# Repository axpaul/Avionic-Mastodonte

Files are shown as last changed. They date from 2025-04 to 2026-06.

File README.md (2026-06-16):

# Mastodonte – Séquenceur

**Mastodonte** est un ordinateur de bord, ou plus précisément un **séquenceur**, destiné à orchestrer de manière autonome les événements critiques d’un vol de fusée expérimentale. Il est conçu pour répondre aux exigences du **cahier des charges du C'Space**, et s’intègre à tout projet nécessitant un séquencement fiable, robuste et temps réel.

---

> *© 2025/2026 - Paul Miailhe.*  
> *This material is licensed under the CERN Open Hardware Licence Version 2 - Strongly Reciprocal (CERN-OHL-S). [→ CERN-OHL-S](https://ohwr.org/licences/)*
> > 

---

<p align="center">
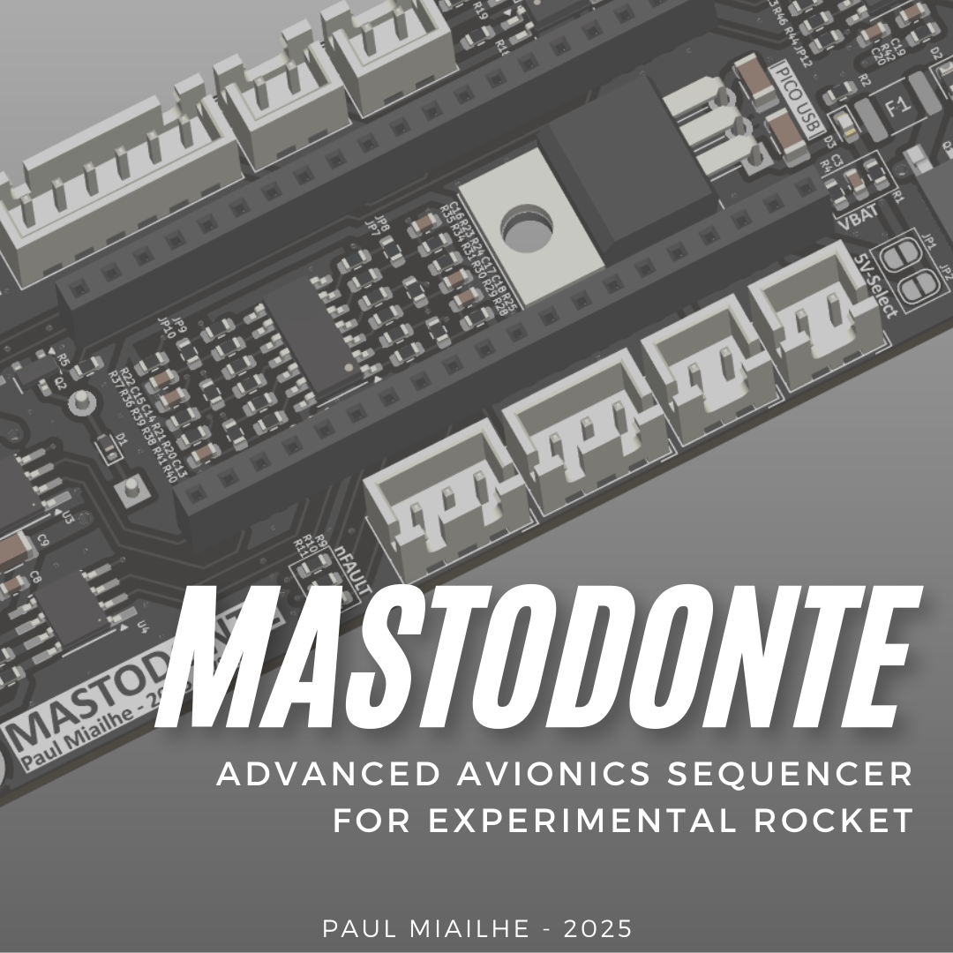
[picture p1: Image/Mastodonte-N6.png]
Carte Mastodonte
  
</p>

---

## Fonctionnement

Mastodonte supervise et déclenche en toute autonomie les étapes clés du vol, sans intervention extérieure :

### Détection du décollage
La détection initiale peut se faire par deux méthodes :
- Un **contact jack** (fil coupe-circuit) : un câble fin relie la fusée au sol, et se sectionne au moment du lancement. La coupure génère une interruption matérielle, qui marque le T-0 du vol.
- Un **accéléro-contact** (contacteur à masselotte) peut également déclencher le séquenceur dès détection d’une accélération.

Dans les deux cas, la carte démarre son chronomètre interne pour initier la séquence.

### Fenêtrage temporel autour de l’apogée
Après le décollage, Mastodonte ouvre une **fenêtre temporelle** durant laquelle la détection de l’apogée est autorisée :
- Un signal extérieur, par exemple issu d’un autre système avionique ou d’un capteur, peut être reçu via un **optocoupleur** pour indiquer l’apogée.
- Ce signal n’est pris en compte **que pendant la fenêtre**, afin d’écarter toute détection parasite en dehors de cette phase critique.
- Si aucune détection n’est reçue, un **déclenchement de sécurité** est effectué après un **temps maximal prédéfini** post-apogée, garantissant ainsi l’ouverture du système de récupération.

### Déploiement du système de récupération
En réponse à une détection d’apogée (ou par sécurité en fin de fenêtre), Mastodonte déclenche le système de récupération :
- Par **charge pyrotechnique** (détonateur, coupe-corde, etc.),
- Ou par **moteur DC** (vis de poussée, libération mécanique, etc.).

### Enregistrement des événements critiques
Mastodonte assure un enregistrement précis des points clés du vol :
- Heure de **décollage** (T-0),
- **Début et fin** de la fenêtre d’apogée,
- **Réception (ou absence)** du signal d’apogée,
- **Déclenchement** du système de récupération,
- **Tension batterie** mesurée durant le vol,
- **Événements d’erreur moteur** détectés.

Ce journal d’exécution agit comme une **boîte noire embarquée**, permettant d’analyser a posteriori le bon déroulement de la mission, et d’identifier toute anomalie de comportement.

---

> Mastodonte vise à offrir un **fonctionnement déterministe**, **fiable** et **autonome**, même en l’absence de télémétrie ou de supervision au sol, conformément à l’esprit du **cahier des charges C'Space**.

---

## Architecture & Fonctionnalités

### Alimentation et protections
- Protection contre l’inversion de polarité (MOSFET P **SQD50P04-13L**)
- Protection contre surtensions (**TVS SMAJ14A**)
- Limitation de courant via fusible réarmable
- Régulation de tension (LM340AT : 7.4 V batterie → 5 V)
- Sélection de la source d’alimentation (USB-C ou batterie)
- LED d’indication d’alimentation

### Microcontrôleur RP2040-YD

Mastodonte s’appuie sur la carte **RP2040-YD**, une carte commerciale compacte embarquant un microcontrôleur **RP2040** de Raspberry Pi, accompagnée de ses périphériques essentiels :

- Double cœur **ARM Cortex-M0+** cadencé à 133 MHz
- **128 Mbits (16 MB)** de mémoire flash externe **W25Q128**
- Oscillateur intégré à **12 MHz**
- Interface native **USB-C**
- Format physique compatible **Raspberry Pi Pico**
- Brochage latéral avec **40 broches GPIO** (20 de chaque côté)
- LED RGB **WS2812** intégrée (GPIO23)
- Boutons embarqués :
  - **BOOT**
  - **RESET**
  - **USER KEY** (GPIO24)
- Interface **SWD** pour débogage

La carte **RP2040-YD** est conçue pour venir se **connecter verticalement** sur le PCB principal appelé **BR-Motor** via deux rangées de connecteurs femelles. Une fois assemblée, l'ensemble forme la carte **Mastodonte**, regroupant la logique de contrôle (RP2040-YD) et l’électronique de puissance et d’interface (BR-Motor).

<p align="center">
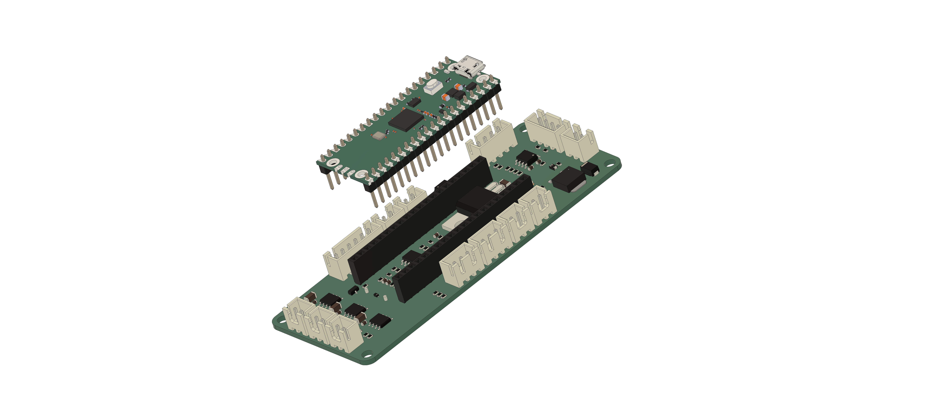
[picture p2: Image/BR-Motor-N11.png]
RP2040-YD plug sur BR-Motor
  
</p>

### Interfaces et connectiques
- Connecteurs au format **JST B2B-XH**
- Connexions dédiées pour moteurs, charges pyrotechniques, capteurs et interfaces de communication
- Tensions disponibles : **5 V** et **3.3 V**

---

## Interfaces et E/S

### Commande moteur / Charge pyrotechnique
- 3 drivers **DRV8872DDA** (ponts en H)
  - Jusqu’à **3.6 A** sous **6.5–45 V**
  - Contrôle **PWM**
  - LED de direction pour visualisation sans charge
  - Détection d’erreurs via broche **nFAULT**

### Signaux d’entrée isolés
- **Optocoupleurs ACPL-214** pour isolation galvanique
- Buffers logiques **74HC14** (Schmitt trigger) pour traitement numérique
- Isolation UART et conversion de niveau : **ADuM1281**
- Pull-ups 4.7 kΩ intégrés sur les lignes I²C

### Buzzer de notification
- Pilotage via transistor **BSS138**
- Protection par diode **1N4148**
- Activation par GPIO (IN_BUZZ)

---

## Schéma fonctionnel

<p align="center">
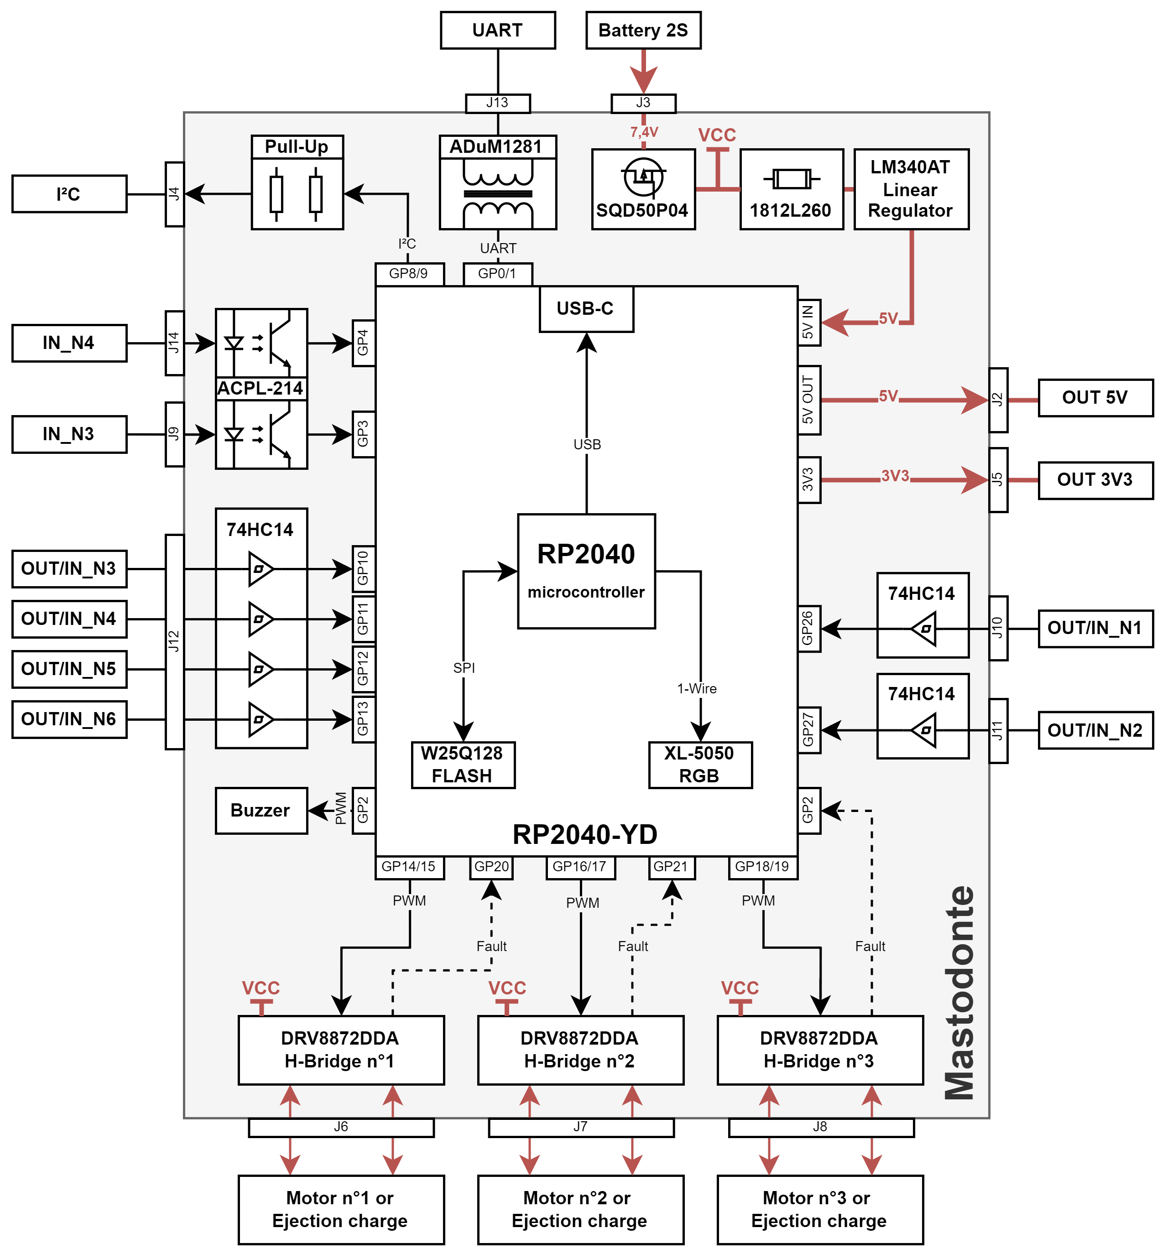
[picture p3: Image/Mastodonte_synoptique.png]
Synoptique Mastodonte
  
</p>

---

## Signaux sortants – Carte Mastodonte (RP2040-YD)

| Signal | Type de signal | Connecteur | GPIO RP2040 | Description |
|---|---|---|---|---|
| `IN1_M1` | PWM / Logique | J6 (Moteur 1) | GP14 | Commande H-Bridge moteur/charge 1 |
| `IN2_M1` | PWM / Logique | J6 (Moteur 1) | GP15 | Commande H-Bridge moteur/charge 1 |
| `IN1_M2` | PWM / Logique | J7 (Moteur 2) | GP16 | Commande H-Bridge moteur/charge 2 |
| `IN2_M2` | PWM / Logique | J7 (Moteur 2) | GP17 | Commande H-Bridge moteur/charge 2 |
| `IN1_M3` | PWM / Logique | J8 (Moteur 3) | GP18 | Commande H-Bridge moteur/charge 3 |
| `IN2_M3` | PWM / Logique | J8 (Moteur 3) | GP19 | Commande H-Bridge moteur/charge 3 |
| `IN_BUZZ` | Logique | J5 (Buzzer) | GP2 | Commande du buzzer (MOSFET BSS138) |
| `OUT_N1` | GPIO | J10 | GP26 | Sortie numérique non isolée |
| `OUT_N2` | GPIO | J10 | GP27 | Sortie numérique non isolée |
| `OUT_N3` | GPIO | J10 | GP10 | Sortie numérique non isolée |
| `OUT_N4` | GPIO | J11 | GP11 | Sortie numérique non isolée |
| `OUT_N5` | GPIO | J11 | GP12 | Sortie numérique non isolée |
| `OUT_N6` | GPIO | J11 | GP13 | Sortie numérique non isolée |
| `OUT_ISO_N3` | GPIO isolée | J13 (Opto) | GP3 | Sortie isolée via optocoupleur |
| `OUT_ISO_N4` | GPIO isolée | J13 (Opto) | GP4 | Sortie isolée via optocoupleur |
| `SDA` | I²C (données) | J12 (I²C) | GP8 | Bus I²C données (avec pull-up) |
| `SCL` | I²C (horloge) | J12 (I²C) | GP9 | Bus I²C horloge (avec pull-up) |
| `IN_ISO_N1` | UART (émission) | J9 (UART) | GP0 | Émission isolée série vers modules externes |
| `OUT_ISO_N2` | UART (réception) | J9 (UART) | GP1 | Réception isolée série depuis modules externes |
| `VCC_BAT` | Alimentation | J2 / J3 (OUT PWR) | — | Tension batterie (après filtrage) exposée |
| `+5V` | Alimentation régulée| J2 / J3 / I²C | — | Tension 5 V régulée disponible |
| `+3.3V` | Alimentation logique| Tous connecteurs  | — | Tension logique (niveau RP2040) |

> Tous les signaux sont sur le standart CMOS 3.3 V côté logique.

## RP2040-YD PINOUT

<p align="center">
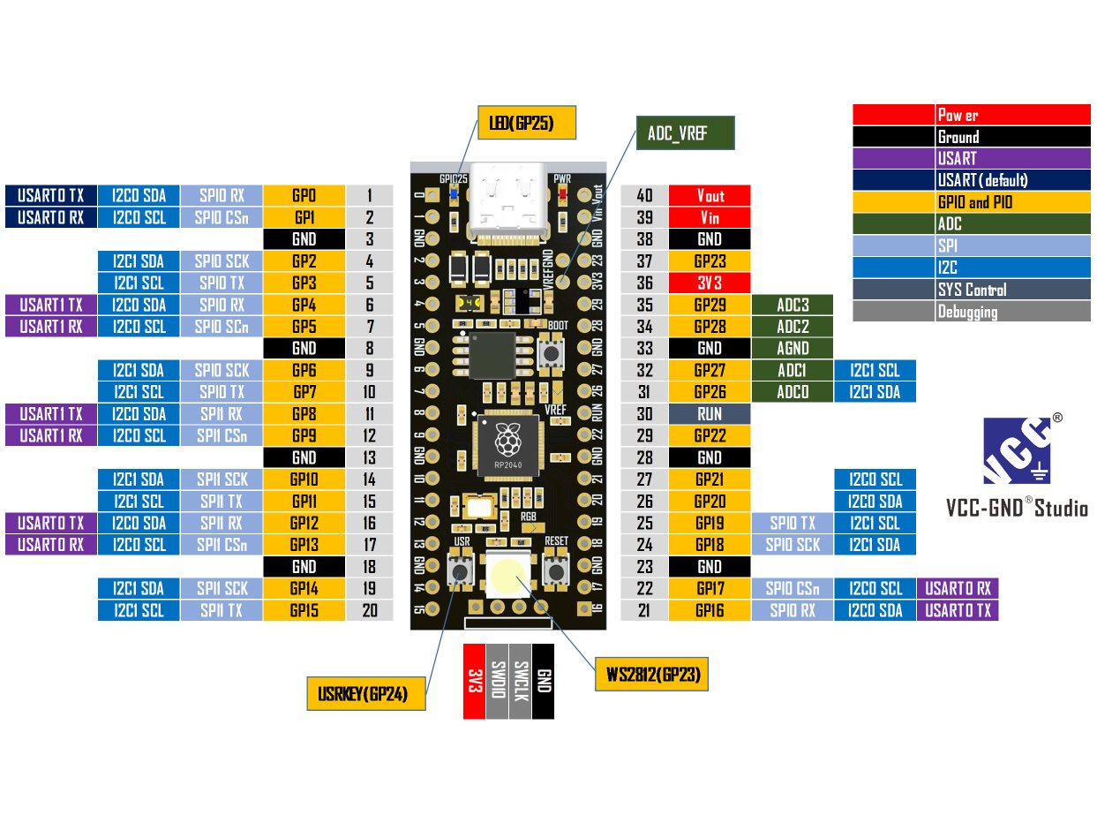
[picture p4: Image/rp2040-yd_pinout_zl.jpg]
RP2040-YD board
  
</p>

---

## Caractéristiques mécaniques

- Dimensions : **100 × 40 mm**
- Épaisseur maximale : **18.13 mm**
- Trous de fixation : 4 × Ø3.2 mm
- Masse sans support : **37 g**
- Fichier **STEP 3D** disponible ici : [`Mechanical/BR-Motor.step`](Mechanical/BR-Motor.step)

<p align="center">
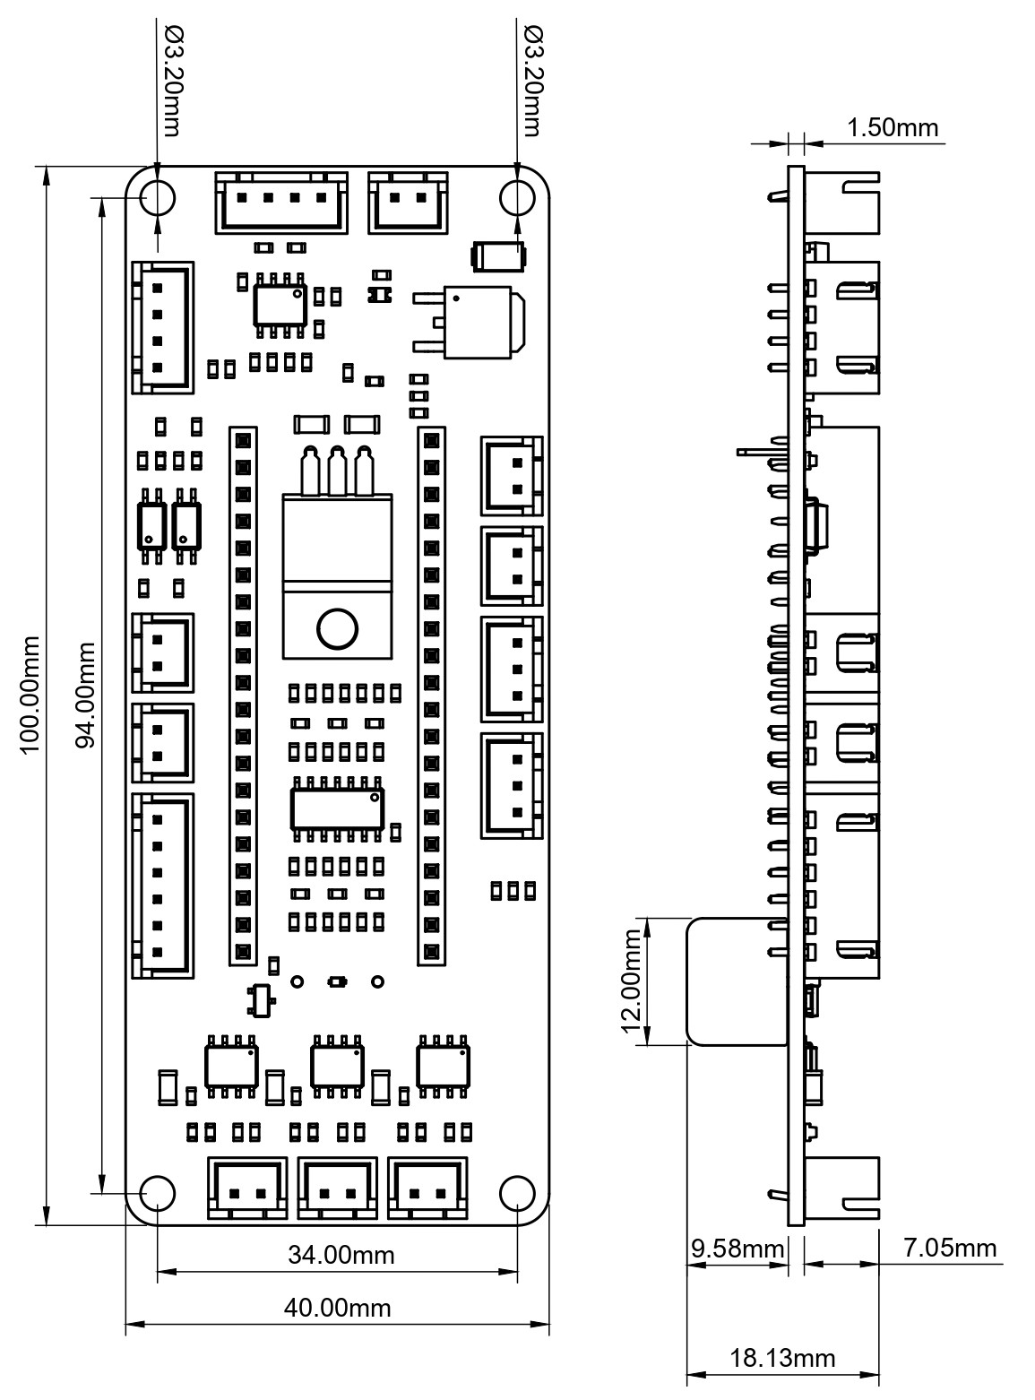
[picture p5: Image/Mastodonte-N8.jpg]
Dimensions mécaniques
  
</p>

---

## Ressources utiles

Composants utilisés sur la carte Mastodonte, avec leurs fiches techniques officielles :

| Composant | Rôle dans le système | Fiche technique |
|---|---|---|
| **DRV8872** | Driver de moteur DC (pont en H jusqu’à 3.6 A) | [→ Datasheet TI](https://www.ti.com/lit/ds/symlink/drv8872.pdf) |
| **RP2040** | Microcontrôleur principal double cœur | [→ Datasheet Raspberry Pi](https://www.raspberrypi.com/documentation/microcontrollers/rp2040.html) |
| **ACPL-214** | Optocoupleur pour isolation galvanique des signaux d’entrée | [→ Datasheet Broadcom](https://www.broadcom.com/products/optocouplers/industrial-plastic/acpl-214) |
| **TLP292(TPL,E** | Optocoupleur pour isolation galvanique des signaux d’entrée | [→ Datasheet Toshiba](https://toshiba.semicon-storage.com/info/TLP292_datasheet_en_20191129.pdf?did=14425&prodName=TLP292) |
| **74HC14** | Buffer logique à trigger de Schmitt pour traitement des signaux numériques | [→ Datasheet TI](https://www.ti.com/lit/ds/symlink/sn74hc14.pdf?ts=1743611017766) |
| **ADuM1281** | Isolateur numérique double canal pour signaux UART | [→ Datasheet Analog Devices](https://www.analog.com/media/en/technical-documentation/data-sheets/ADuM1280_1281_1285_1286.pdf) |
| **LM340AT** | Régulateur de tension linéaire 5V | [→ Datasheet TI](https://www.ti.com/lit/ds/symlink/lm340.pdf) |
| **1812L260/16MR** | Fusible réarmable pour limitation de courant | [→ Datasheet Littelfuse](https://www.littelfuse.com/assetdocs/resettable-ptcs-1812l-datasheet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) |
| **SQD50P04-13L** | MOSFET P pour protection contre l’inversion de polarité | [→ Datasheet Vishay](https://www.vishay.com/docs/65157/sqd50p04-13l.pdf) |
| **BSS138** | Transistor N-MOS pour commutation de charges faibles (buzzer, etc.) | [→ Datasheet OnSemi](https://www.onsemi.com/pdf/datasheet/bss138-d.pdf) |

> Sur la production 02/03/2025, les optocoupleurs utilisés sont les TLP292(TPL,E).

---

# [OPTION] : BR Mini Sensor

La **BR Mini Sensor** est une carte mezzanine entièrement compatible avec la Raspberry Pi Pico. Il s'agit d'un **COMPLEMENT**. Le stack sans fonctionne parfaitement sans, mais cet ajout permet d'étendre ses capacités.
Elle embarque une suite de capteurs communicant via le bus **I²C** :
* **Un accéléromètre 3 axes & un gyromètre 3 axes** (IMU) : Basés sur le composant **LSM6DSL** de STMicroelectronics.
* **Un capteur de pression** permettant de mesurer l'altitude : Basé sur le composant **LPS22HB** de STMicroelectronics.

<p align="center">
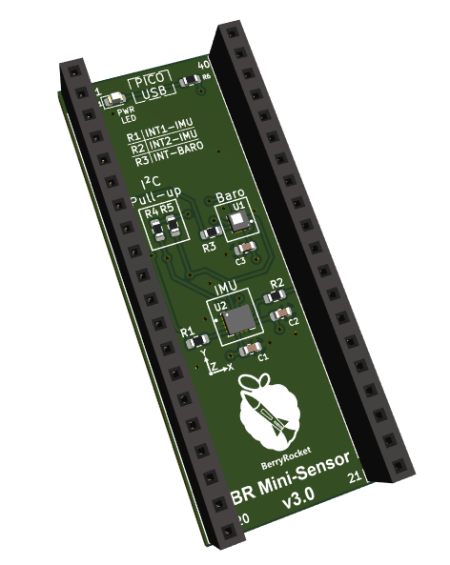
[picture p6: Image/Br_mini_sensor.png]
BR Mini Sensor
  
</p>

La carte BR Mini Sensor vous permettra, moyennant un peu de code, de mesurer et d'enregistrer les paramètres de vol de votre fusée afin d'en estimer la trajectoire.
Pour plus de détails, consultez la documentation officielle : [Wiki BR Mini Sensor](https://berryrocket.com/wiki/BR_Mini_Sensor).

## Configuration matérielle et précautions

Lors de l'intégration de la carte, une attention particulière doit être portée à la gestion des broches d'interruption :

* **Isolement des interruptions (INT1 / INT2) :** Il est nécessaire de prévoir le **dessoudage de certaines résistances 0R** sur la carte pour les lignes `INT1` et `INT2` de l'IMU.
* **Prévention des conflits :** Cette modification permet d'éviter de polluer d'autres pins de la carte BR-Motor et d'interférer avec l'**optocoupleur** ou le signal **Nfault du moteur 3**.

---

## Test Fly Video

La vidéo de qualification de Mastodonte pour le projet Diamant :

### [Visionner le Test Avionique Mastodonte sur YouTube](https://www.youtube.com/watch?v=LKwvPUTVWk4)

<p align="center">
  <a href="https://www.youtube.com/watch?v=LKwvPUTVWk4">
    Test Avionique Mastodonte
  </a>
</p>

*Test des systèmes embarqués de la fusée Mastodonte.*

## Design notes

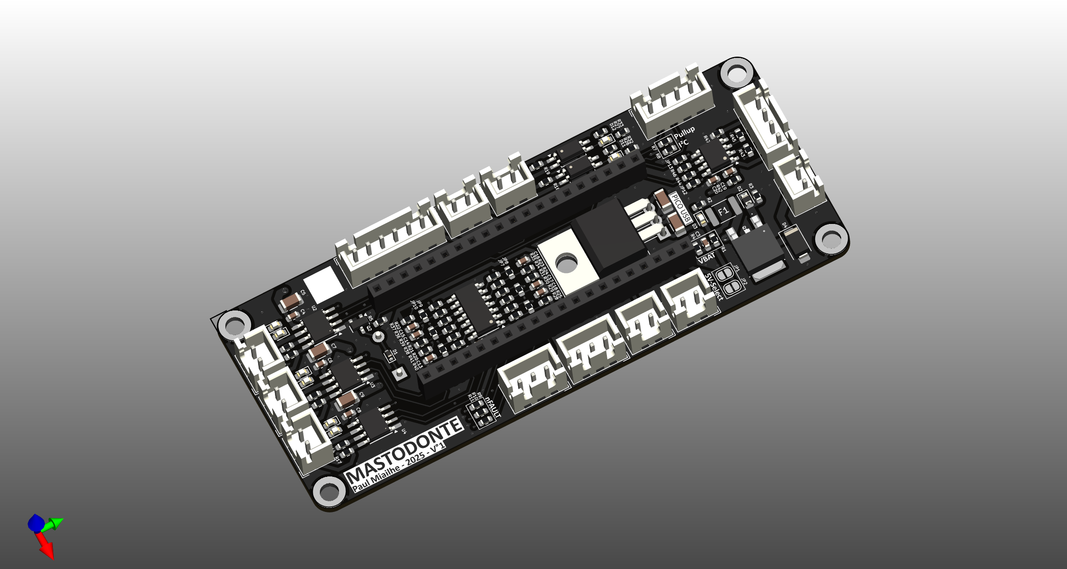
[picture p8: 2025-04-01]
Image/BR-Motor-N8.png

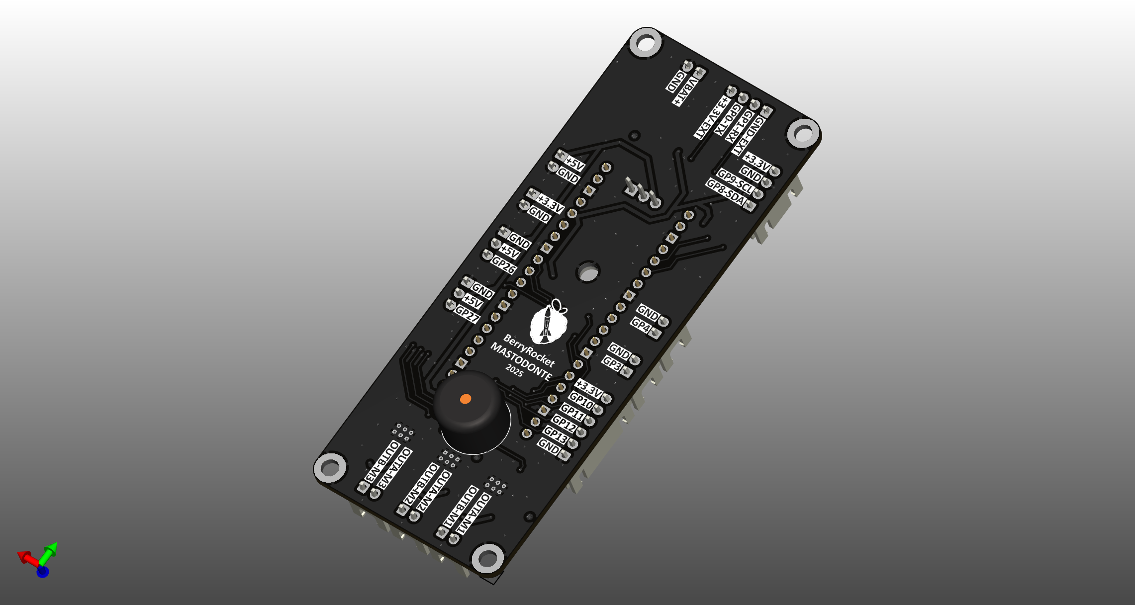
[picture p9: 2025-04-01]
Image/BR-Motor-N9.png

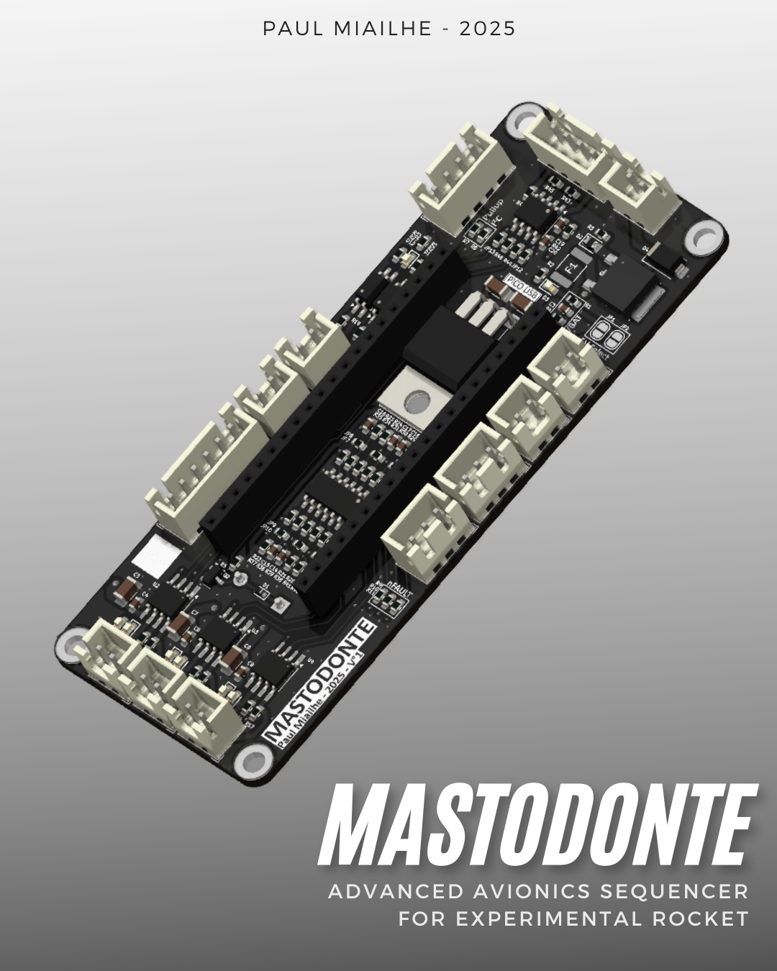
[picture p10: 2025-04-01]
Image/Mastodonte-N1.png

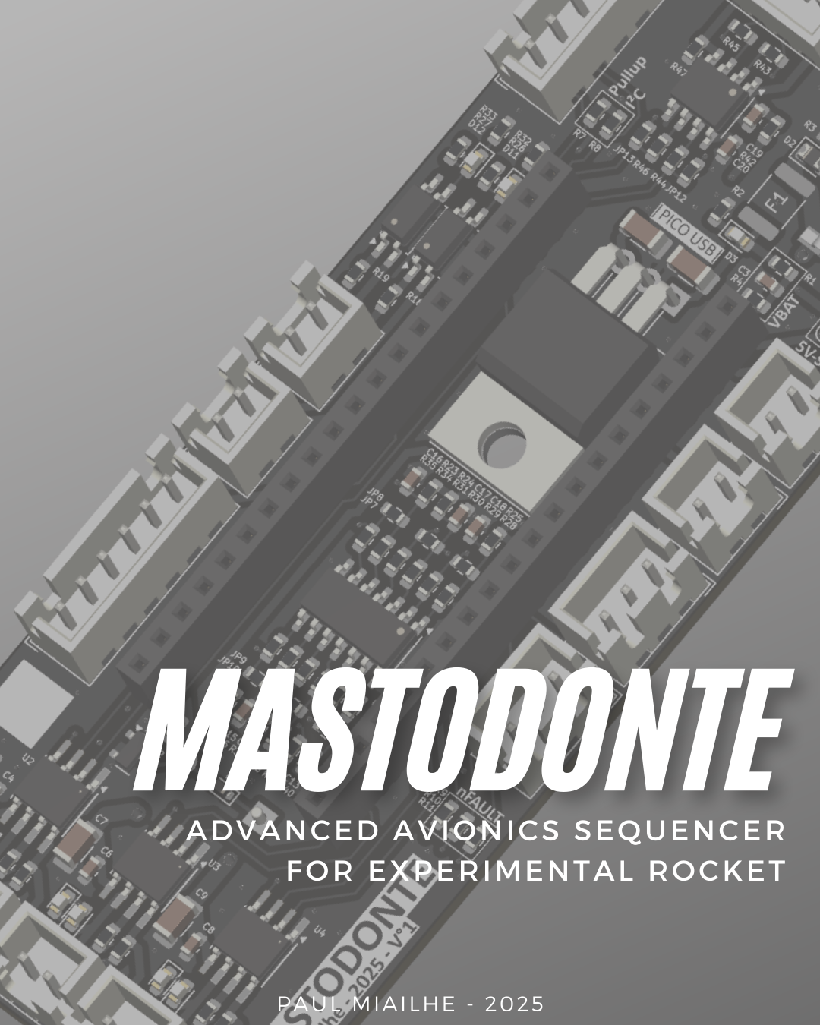
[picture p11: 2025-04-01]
Image/Mastodonte-N4.png

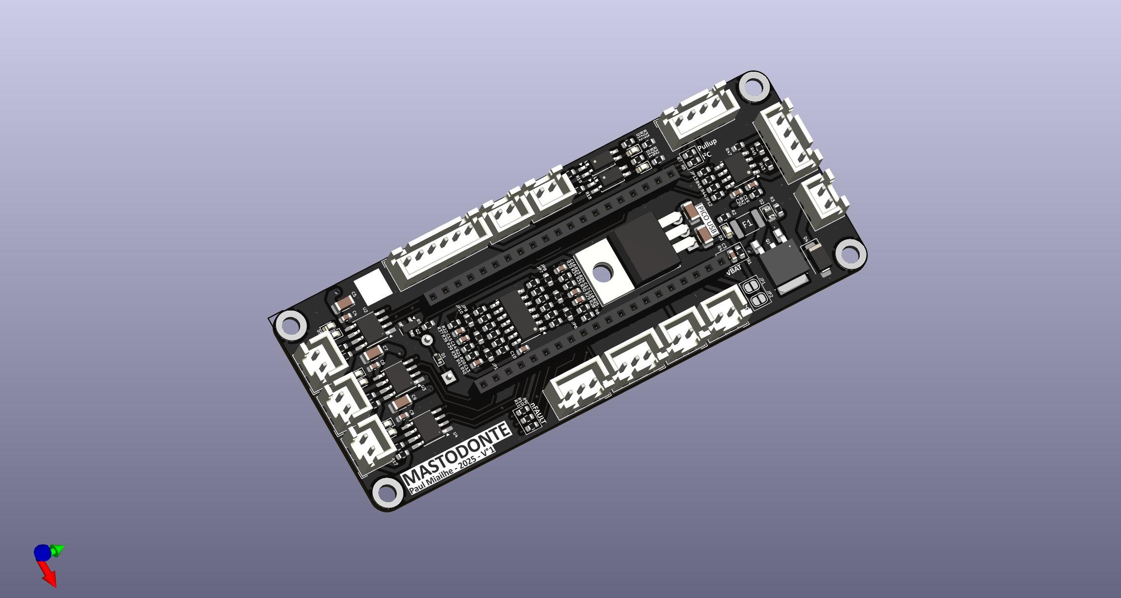
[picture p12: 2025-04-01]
Image/BR-Motor-N1.jpg

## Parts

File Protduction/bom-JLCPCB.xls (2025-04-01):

Comment | Designator | Footprint | JLCPCB Part #
100nF | C2 | 1206 | C24497
BSS138 | Q2 | SOT-23 | C7420339
LED-G | D10,D6,D8 | 0603 | C5123548
1812L260/16MR | F1 | 1812 | C207075
74HC14 | U7 | SOIC-14_3.9x8.7mm_P1.27mm | C5356103
SMAJ14A | D4 | D_SMA | C364286
ADuM1281 | U8 | SOIC-8_3.9x4.9mm_P1.27mm | C89477
220nF | C1 | 1206 | C1857
1N4148WT | D1 | D_SOD-523 | C7420320
LED-B | D3 | 0603 | C2288
100nF | C10,C19,C20,C4,C6,C8 | 0603 | C14663
DRV8872DDA | U2,U3,U4 | Texas_HTSOP-8-1EP_3.9x4.9mm_P1.27mm_EP2.95x4.9mm_Mask2.4x3.1mm_ThermalVias | C114179
47uF | C5,C7,C9 | 1206 | C76659
LED-R | D11,D12,D5,D7,D9 | 0603 | C2286
ACPL-214-500E | U5,U6 | SOP-4_4.4x2.6mm_P1.27mm | C3008596
1uF | C13,C14,C15,C16,C17,C18,C3 | 0603 | C15849
4K7 | R7,R8 | 0603 | C23162
10k | R1,R20,R21,R22,R23,R24,R25,R28,R30,R34,R36,R38,R40,R5 | 0603 | C25804
0R | R10,R11,R12,R13,R14,R26,R27,R29,R3,R31,R35,R37,R39,R41,R43,R44,R45,R46,R9 | 0603 | C21189
1k | R2,R32,R33 | 0603 | C21190
750R | R15,R16,R17 | 0603 | C23241
470R | R18,R19 | 0603 | C23179
SQD50P04-13L_T4GE3 | Q1 | SQD50P0413L_T4GE3 | C3291030
2k | R4 | 0603 | C22975

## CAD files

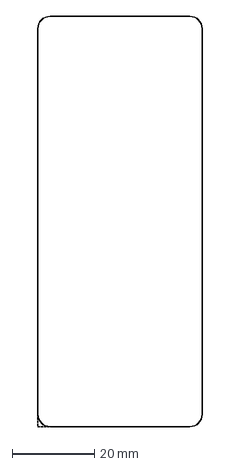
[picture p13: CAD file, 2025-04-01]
Mechanical/PCB-MASTODONTE.dxf
40.0 x 100.0 mm

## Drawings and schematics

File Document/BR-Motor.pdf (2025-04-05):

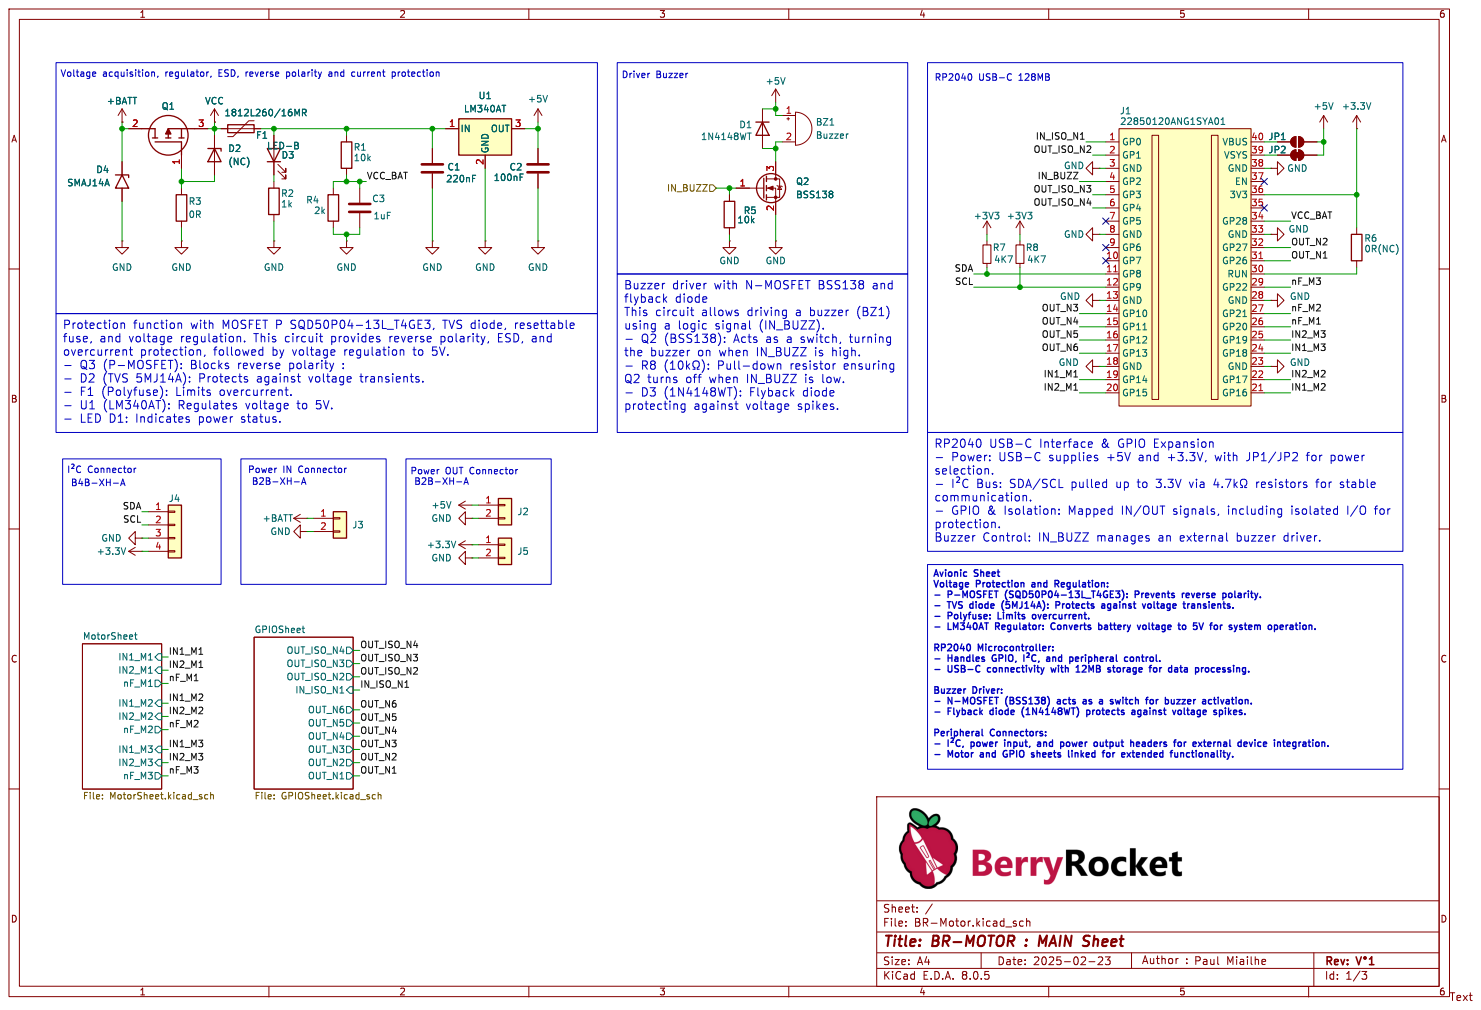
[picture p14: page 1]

Buzzer driver with N-MOSFET BSS138 and
flyback diode

protection.
Buzzer Control: IN_BUZZ manages an external buzzer driver.

- þÿI²C, power input, and power output headers for external device integration. - Motor and GPIO sheets linked for extended functionality.

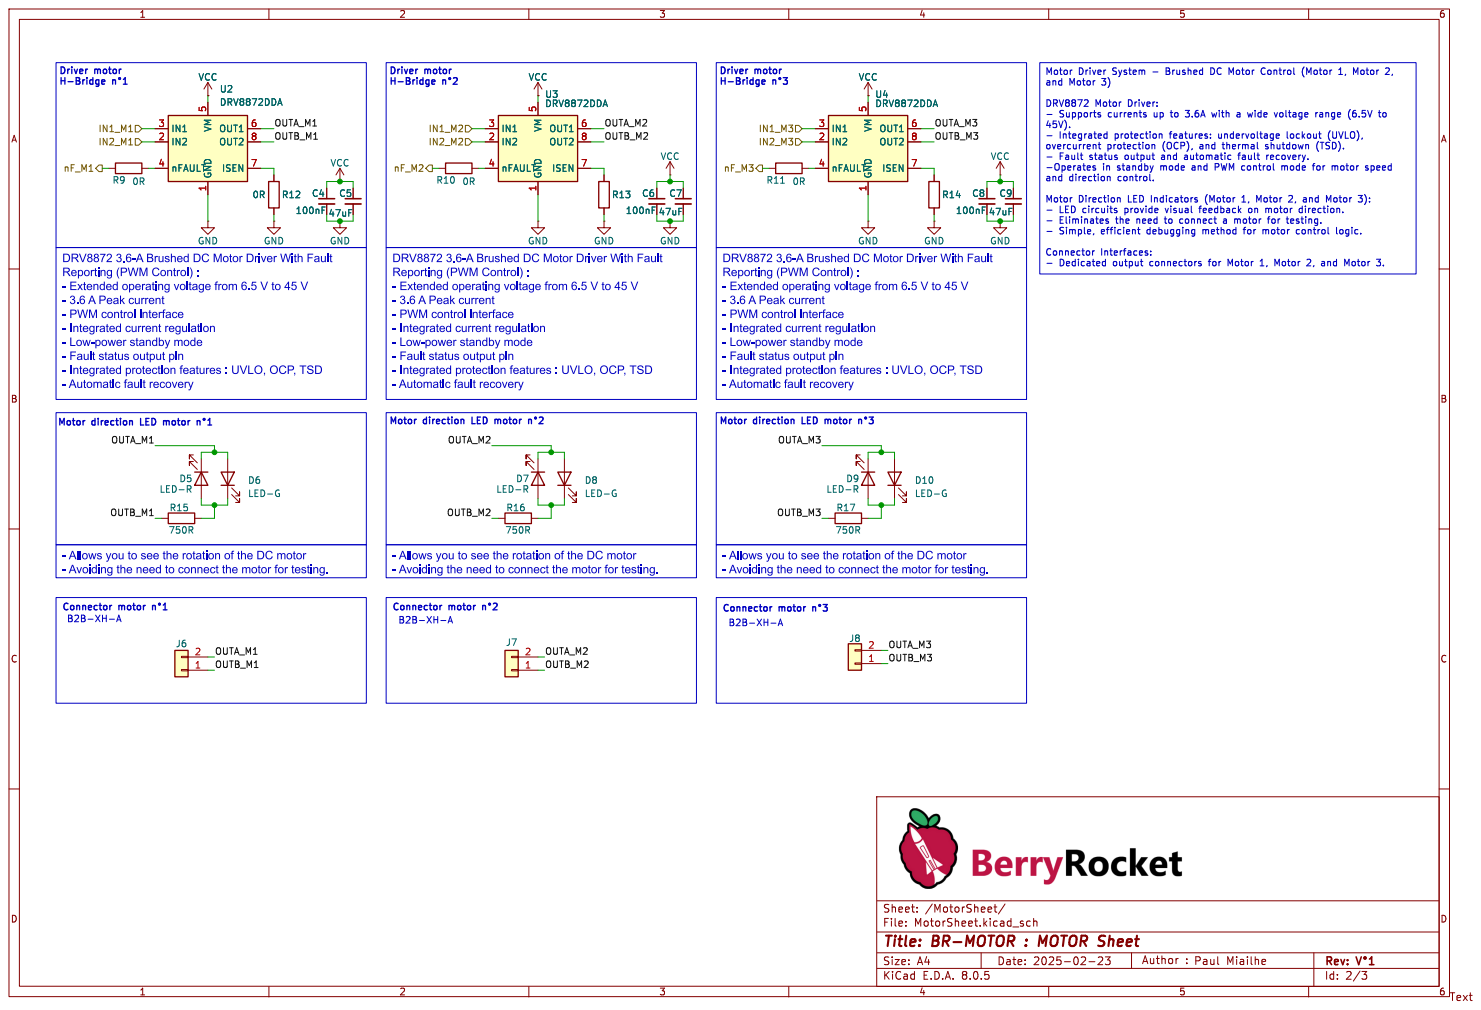
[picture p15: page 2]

DRV8872 3.6-A Brushed DC Motor Driver With Fault
Reporting (PWM Control) : - Extended operating voltage from 6.5 V to 45 V

- 3.6 A Peak current - PWM control interface

- Integrated current regulation
- Low-power standby mode
- Fault status output pin
- Integrated protection features : UVLO, OCP, TSD
- Automatic fault recovery

- Allows you to see the rotation of the DC motor

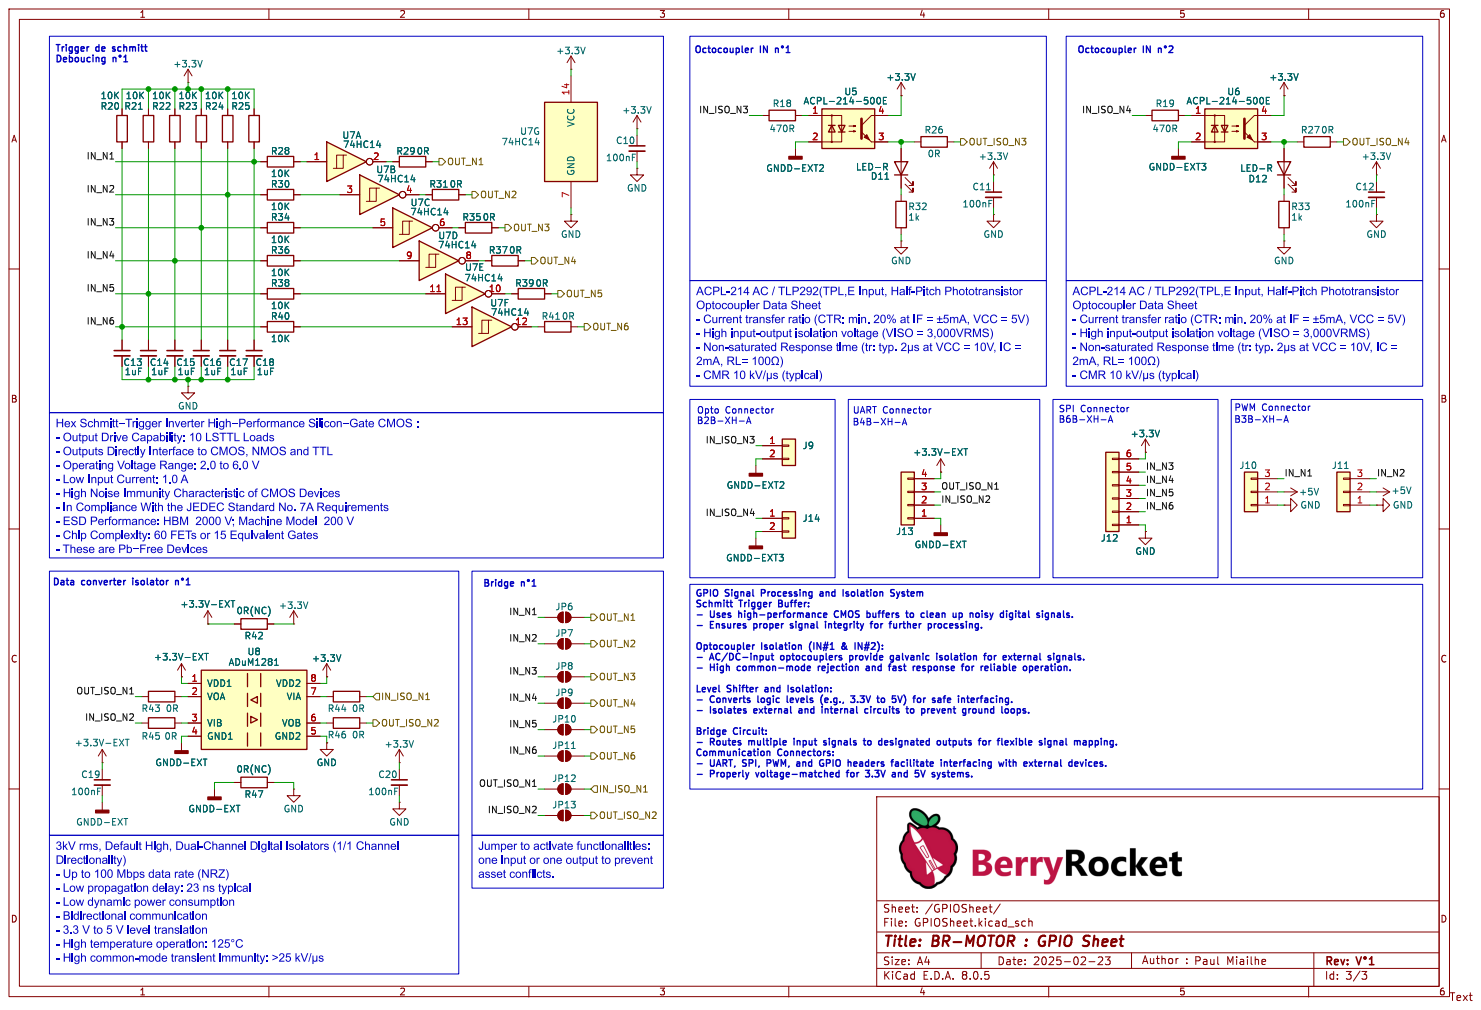
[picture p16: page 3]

Optocoupler Data Sheet - Current transfer ratio (CTR: min. 20% at IF = þÿ±5mA, VCC = 5V)

ACPL-214 AC / TLP292(TPL,E Input, Half-Pitch Phototransistor

- High input-output isolation voltage (VISO = 3,000VRMS)
- Non-saturated Response time (tr: typ. þÿ2¼s at VCC = 10V, IC =
- CMR 10 þÿkV/¼s (typical)

Hex þÿSchmitt"Trigger Inverter þÿHigh"Performance þÿSilicon"Gate CMOS : - Output Drive Capability: 10 LSTTL Loads

- Outputs Directly Interface to CMOS, NMOS and TTL
- Operating Voltage Range: 2.0 to 6.0 V
- Low Input Current: 1.0 A
- High Noise Immunity Characteristic of CMOS Devices
- In Compliance With the JEDEC Standard No. 7A Requirements
- ESD Performance: HBM 2000 V; Machine Model 200 V
- Chip Complexity: 60 FETs or 15 Equivalent Gates
- These are þÿPb"Free Devices

Optocoupler Isolation (IN#1 & IN#2):

- Converts logic levels (e.g., 3.3V to 5V) for safe interfacing. - Isolates external and internal circuits to prevent ground loops.

3kV rms, Default High, Dual-Channel Digital Isolators (1/1 Channel
Directionality)
- Up to 100 Mbps data rate (NRZ)
- Low propagation delay: 23 ns typical - Low dynamic power consumption

Jumper to activate functionalities: one input or one output to prevent asset conflicts.

- Bidirectional communication
- 3.3 V to 5 V level translation
- High temperature operation: þÿ125°C

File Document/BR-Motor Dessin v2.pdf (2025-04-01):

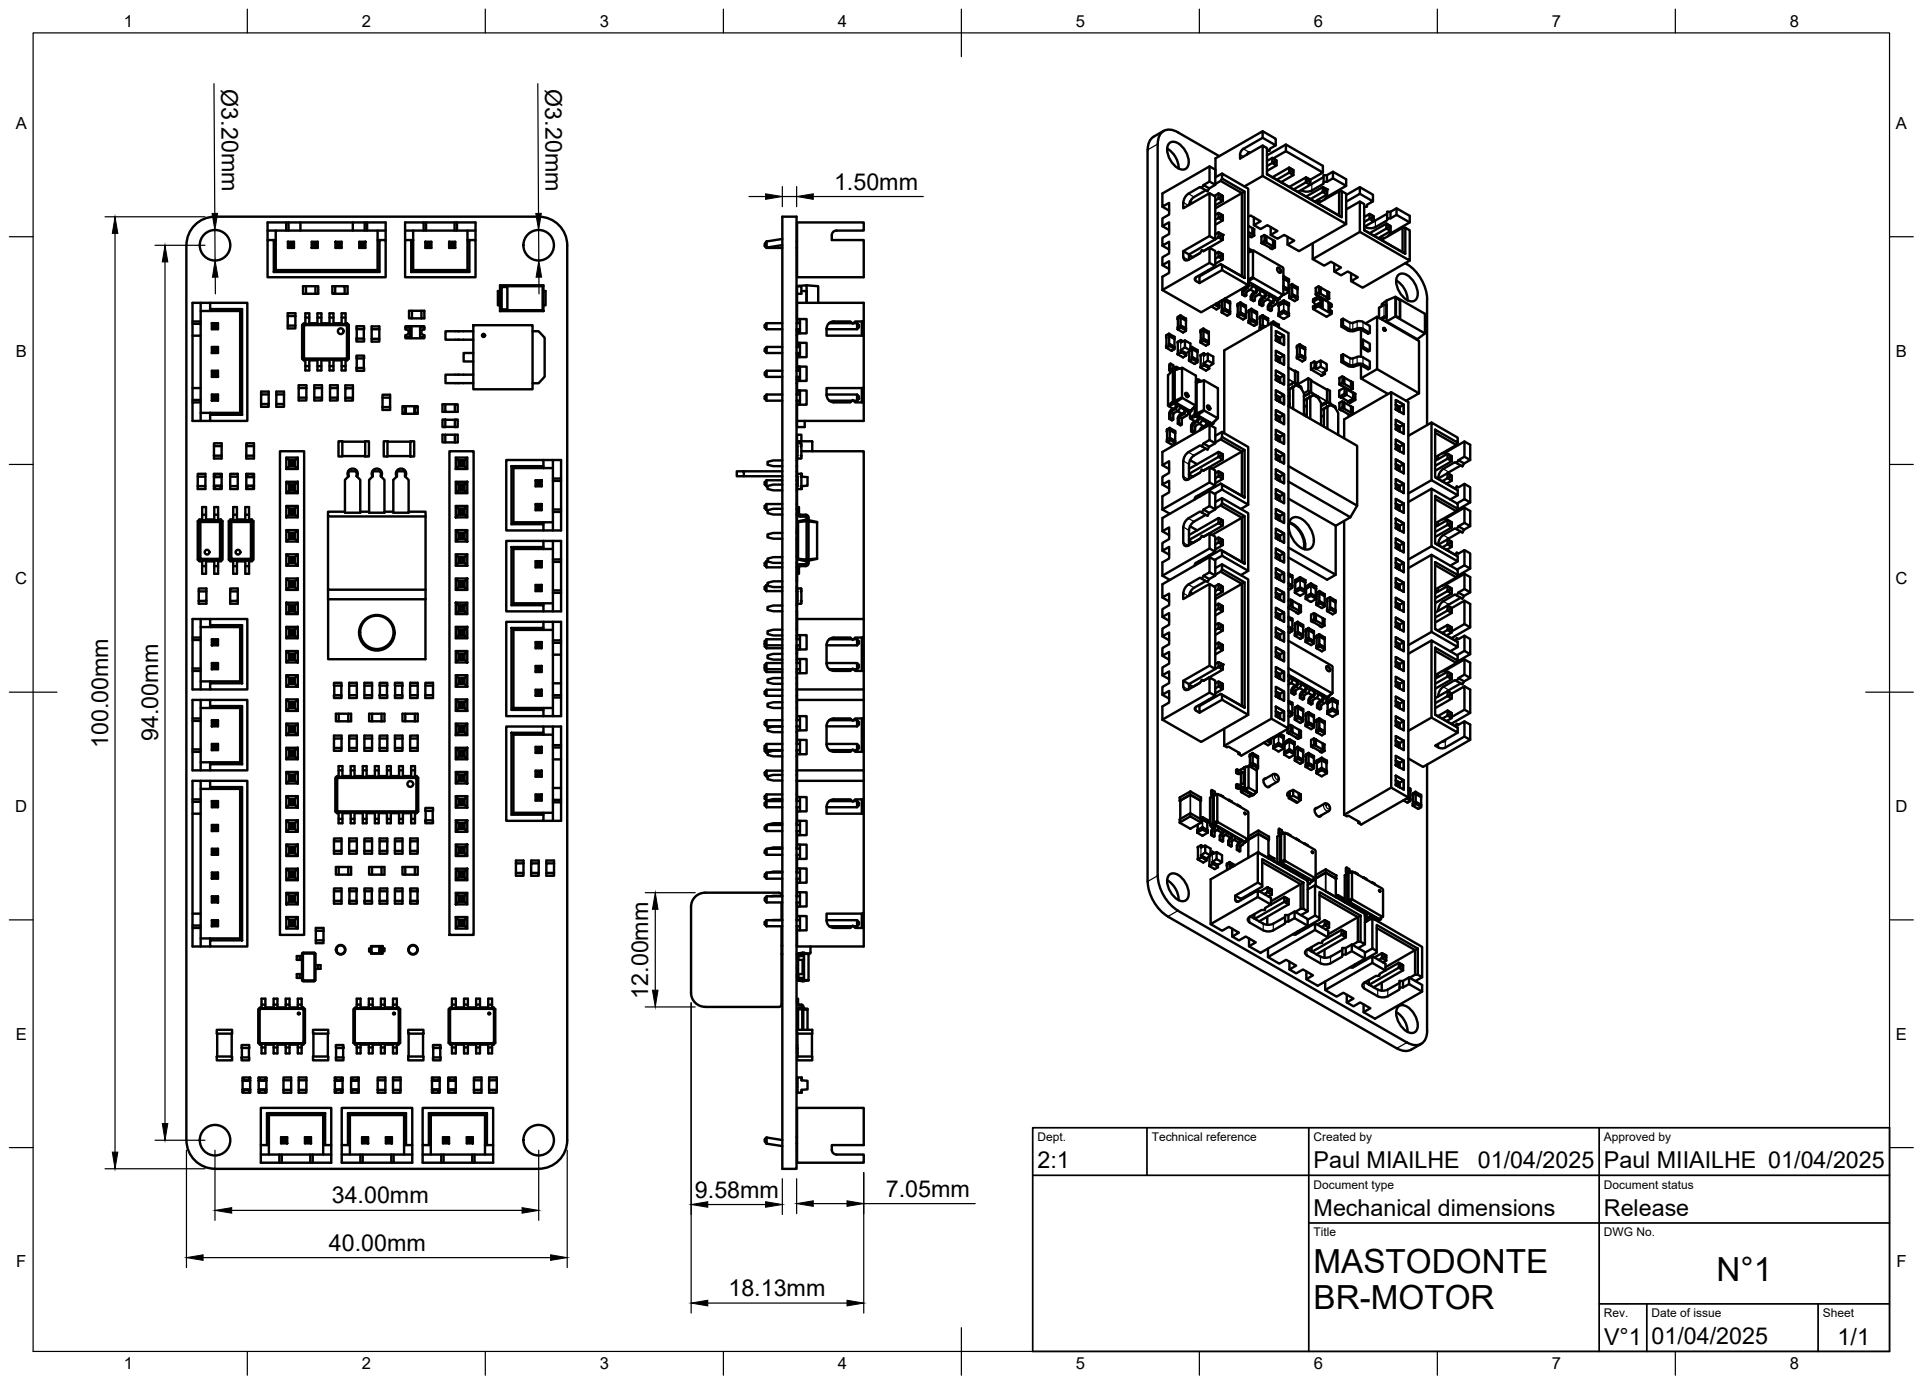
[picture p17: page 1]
Dept.; Technical reference; Created by; Approved by; Document type; Document status; Title; DWG No.; Rev.; Date of issue; Sheet; Mechanical dimensions; Release; Paul MIAILHE; Paul MIIAILHE

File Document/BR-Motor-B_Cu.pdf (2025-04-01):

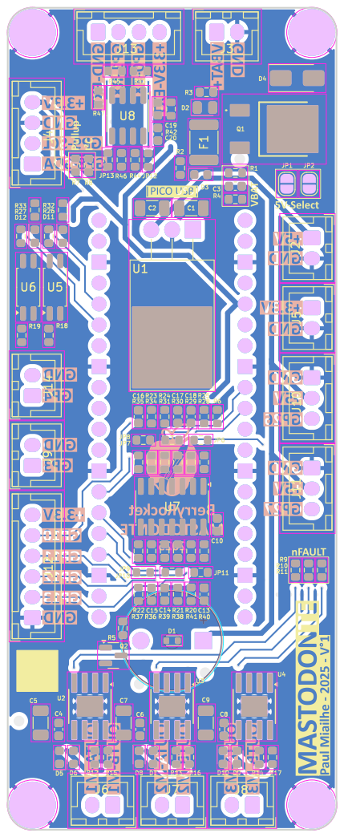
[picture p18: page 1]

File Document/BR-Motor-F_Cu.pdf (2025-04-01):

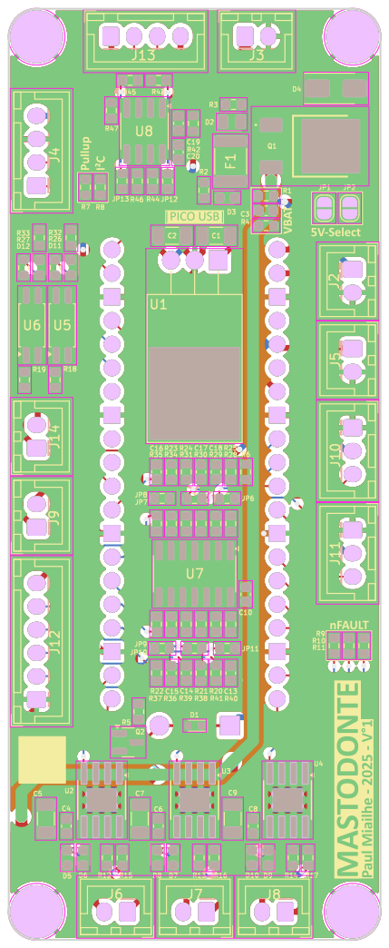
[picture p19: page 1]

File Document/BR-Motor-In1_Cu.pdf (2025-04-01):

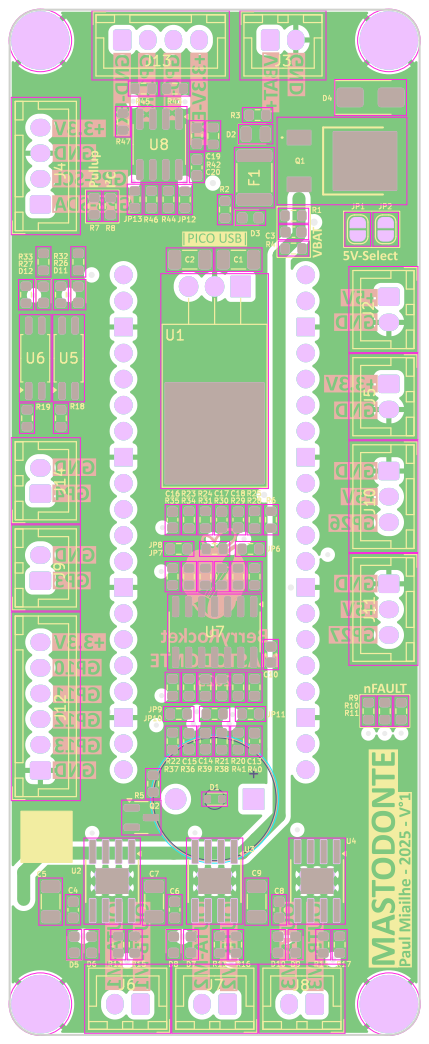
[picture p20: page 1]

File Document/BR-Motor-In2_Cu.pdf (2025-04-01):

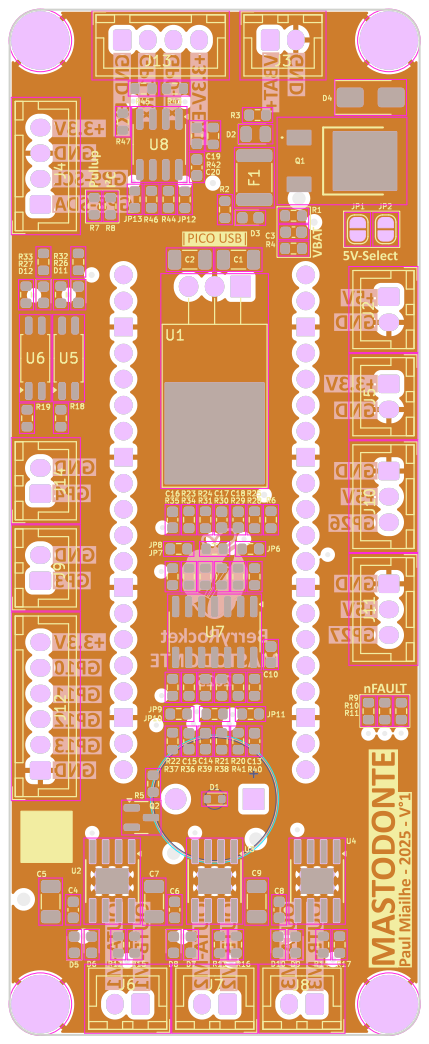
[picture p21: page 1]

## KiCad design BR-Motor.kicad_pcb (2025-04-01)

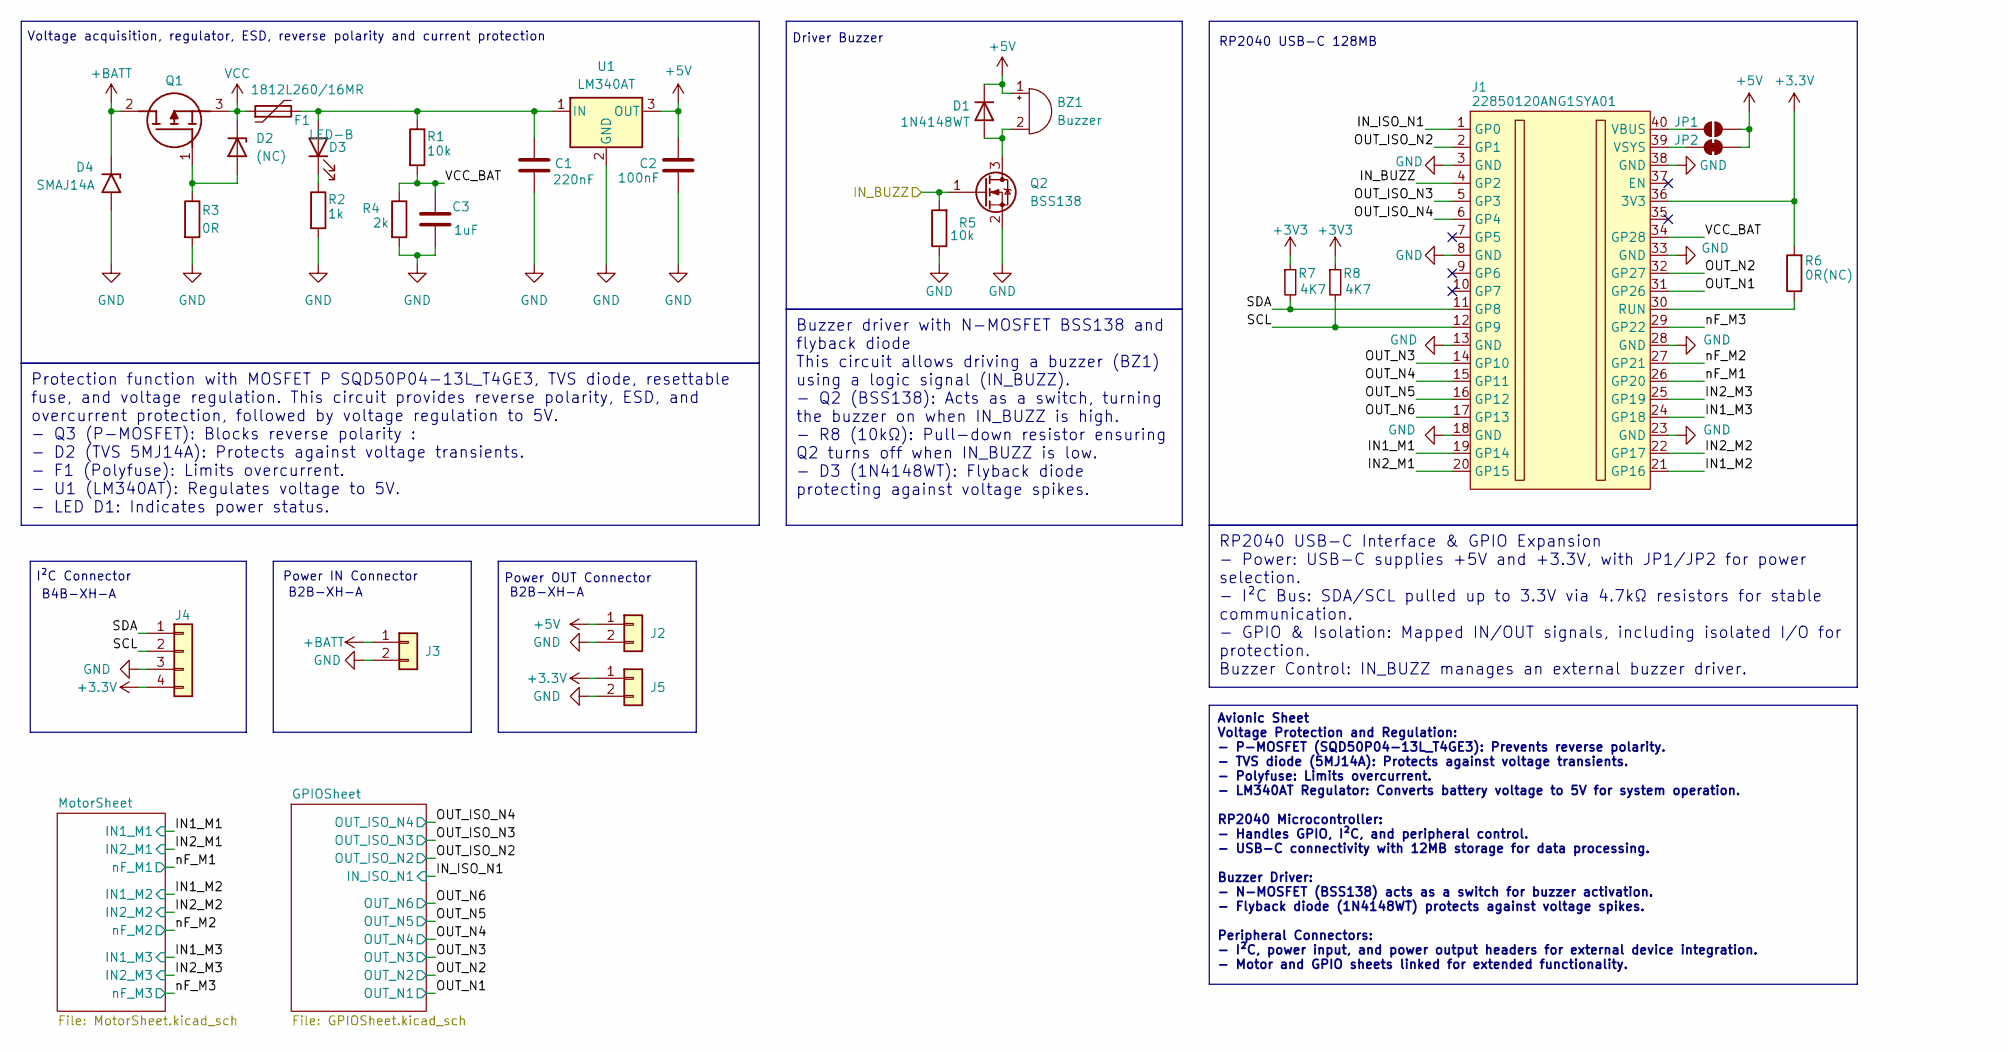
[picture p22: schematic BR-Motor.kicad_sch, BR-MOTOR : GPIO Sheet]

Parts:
BZ1: Buzzer; Buzzer_12x9.5RM7.6
C1: 220nF; C_1206_3216Metric
C2: 100nF; C_1206_3216Metric
C3: 1uF; C_0603_1608Metric
D1: 1N4148WT; D_SOD-523
D2: (NC); D_0805_2012Metric
D3: LED-B; LED_0603_1608Metric
D4: SMAJ14A; D_SMA
F1: 1812L260/16MR; Fuse_1812_4532Metric
J1: 22850120ANG1SYA01; RPi_Pico_TH
J2, J3, J5: Conn_01x02; JST_XH_B2B-XH-A_1x02_P2.50mm_Vertical
J4: Conn_01x04; JST_XH_B4B-XH-A_1x04_P2.50mm_Vertical
JP1: SolderJumper_2_Open; SolderJumper-2_P1.3mm_Open_RoundedPad1.0x1.5mm
JP2: SolderJumper_2_Bridged; SolderJumper-2_P1.3mm_Bridged_RoundedPad1.0x1.5mm
Q1: SQD50P04-13L_T4GE3; SQD50P0413L_T4GE3; Manufacturer_Part_Number SQD50P04-13L_T4GE3; Mouser Part Number 78-SQD50P04-13LT4GE3
Q2: BSS138; SOT-23
R1, R5: 10k; R_0603_1608Metric
R2: 1k; R_0603_1608Metric
R3: 0R; R_0603_1608Metric
R4: 2k; R_0603_1608Metric
R6: 0R(NC); R_0603_1608Metric
R7, R8: 4K7; R_0603_1608Metric
U1: LM340AT; TO-220-3_Horizontal_TabDown

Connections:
+3.3V: J1.36 (3V3), J4.4, J5.1, R6.2; also elsewhere on the board
+3V3: R7.1, R8.1
+5V: BZ1.1 (+), C2.1, D1.1 (K), J2.1, JP1.2 (B), JP2.2 (B), U1.3 (OUT); also elsewhere on the board
+BATT: D4.1 (A1), J3.1, Q1.2 (D)
/IN1_M1: J1.19 (GP14); also elsewhere on the board
/IN1_M2: J1.21 (GP16); also elsewhere on the board
/IN1_M3: J1.24 (GP18); also elsewhere on the board
/IN2_M1: J1.20 (GP15); also elsewhere on the board
/IN2_M2: J1.22 (GP17); also elsewhere on the board
/IN2_M3: J1.25 (GP19); also elsewhere on the board
/IN_BUZZ: J1.4 (GP2), Q2.1 (G), R5.2
/IN_ISO_N1: J1.1 (GP0); also elsewhere on the board
/OUT_ISO_N2: J1.2 (GP1); also elsewhere on the board
/OUT_ISO_N3: J1.5 (GP3); also elsewhere on the board
/OUT_ISO_N4: J1.6 (GP4); also elsewhere on the board
/OUT_N1: J1.31 (GP26); also elsewhere on the board
/OUT_N2: J1.32 (GP27); also elsewhere on the board
/OUT_N3: J1.14 (GP10); also elsewhere on the board
/OUT_N4: J1.15 (GP11); also elsewhere on the board
/OUT_N5: J1.16 (GP12); also elsewhere on the board
/OUT_N6: J1.17 (GP13); also elsewhere on the board
/SCL: J1.12 (GP9), J4.2, R8.2
/SDA: J1.11 (GP8), J4.1, R7.2
/VCC_BAT: C3.1, J1.34 (GP28), R1.2, R4.1
/nF_M1: J1.26 (GP20); also elsewhere on the board
/nF_M2: J1.27 (GP21); also elsewhere on the board
/nF_M3: J1.29 (GP22); also elsewhere on the board
GND: C1.2, C2.2, C3.2, D4.2 (A2), J1.3 (GND), J1.8 (GND), J1.13 (GND), J1.18 (GND), J1.23 (GND), J1.28 (GND), J1.33 (GND), J1.38 (GND), J2.2, J3.2, J4.3, J5.2, Q2.2 (S), R2.2, R3.2, R4.2, R5.1, U1.2 (GND); also elsewhere on the board
unnamed: BZ1.2 (-), D1.2 (A), Q2.3 (D)
unnamed: D2.2 (A), Q1.1 (G), R3.1
unnamed: C1.1, D3.2 (A), F1.2, R1.1, U1.1 (IN)
unnamed: D3.1 (K), R2.1
unnamed: J1.30 (RUN), R6.1
unnamed: J1.40 (VBUS), JP1.1 (A)
unnamed: J1.39 (VSYS), JP2.1 (A)
VCC: D2.1 (K), F1.1, Q1.3 (S); also elsewhere on the board

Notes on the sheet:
Avionic Sheet Voltage Protection and Regulation: - P-MOSFET (SQD50P04-13L_T4GE3): Prevents reverse polarity. - TVS diode (5MJ14A): Protects against voltage transients. - Polyfuse: Limits overcurrent. - LM340AT Regulator: Converts battery voltage to 5V for system operation. RP2040 Microcontroller: -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
Protection function with MOSFET P SQD50P04-13L_T4GE3, TVS diode, resettable fuse, and voltage regulation. This circuit provides reverse polarity, ESD, and overcurrent protection, followed by voltage regulation to 5V. - Q3 (P-MOSFET): Blocks reverse polarity : - D2 (TVS 5MJ14A): Protects against vol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
RP2040 USB-C Interface & GPIO Expansion - Power: USB-C supplies +5V and +3.3V, with JP1/JP2 for power selection. - I²C Bus: SDA/SCL pulled up to 3.3V via 4.7kΩ resistors for stable communication. - GPIO & Isolation: Mapped IN/OUT signals, including isolated I/O for protection. Buzzer Control: IN_BU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
Buzzer driver with N-MOSFET BSS138 and flyback diode This circuit allows driving a buzzer (BZ1) using a logic signal (IN_BUZZ). - Q2 (BSS138): Acts as a switch, turning the buzzer on when IN_BUZZ is high. - R8 (10kΩ): Pull-down resistor ensuring Q2 turns off when IN_BUZZ is low. - D3 (1N4148WT): Fl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
I²C Connector
Voltage acquisition, regulator, ESD, reverse polarity and current protection
Power IN Connector
Power OUT Connector
B2B-XH-A
Driver Buzzer
B4B-XH-A
RP2040 USB-C 128MB

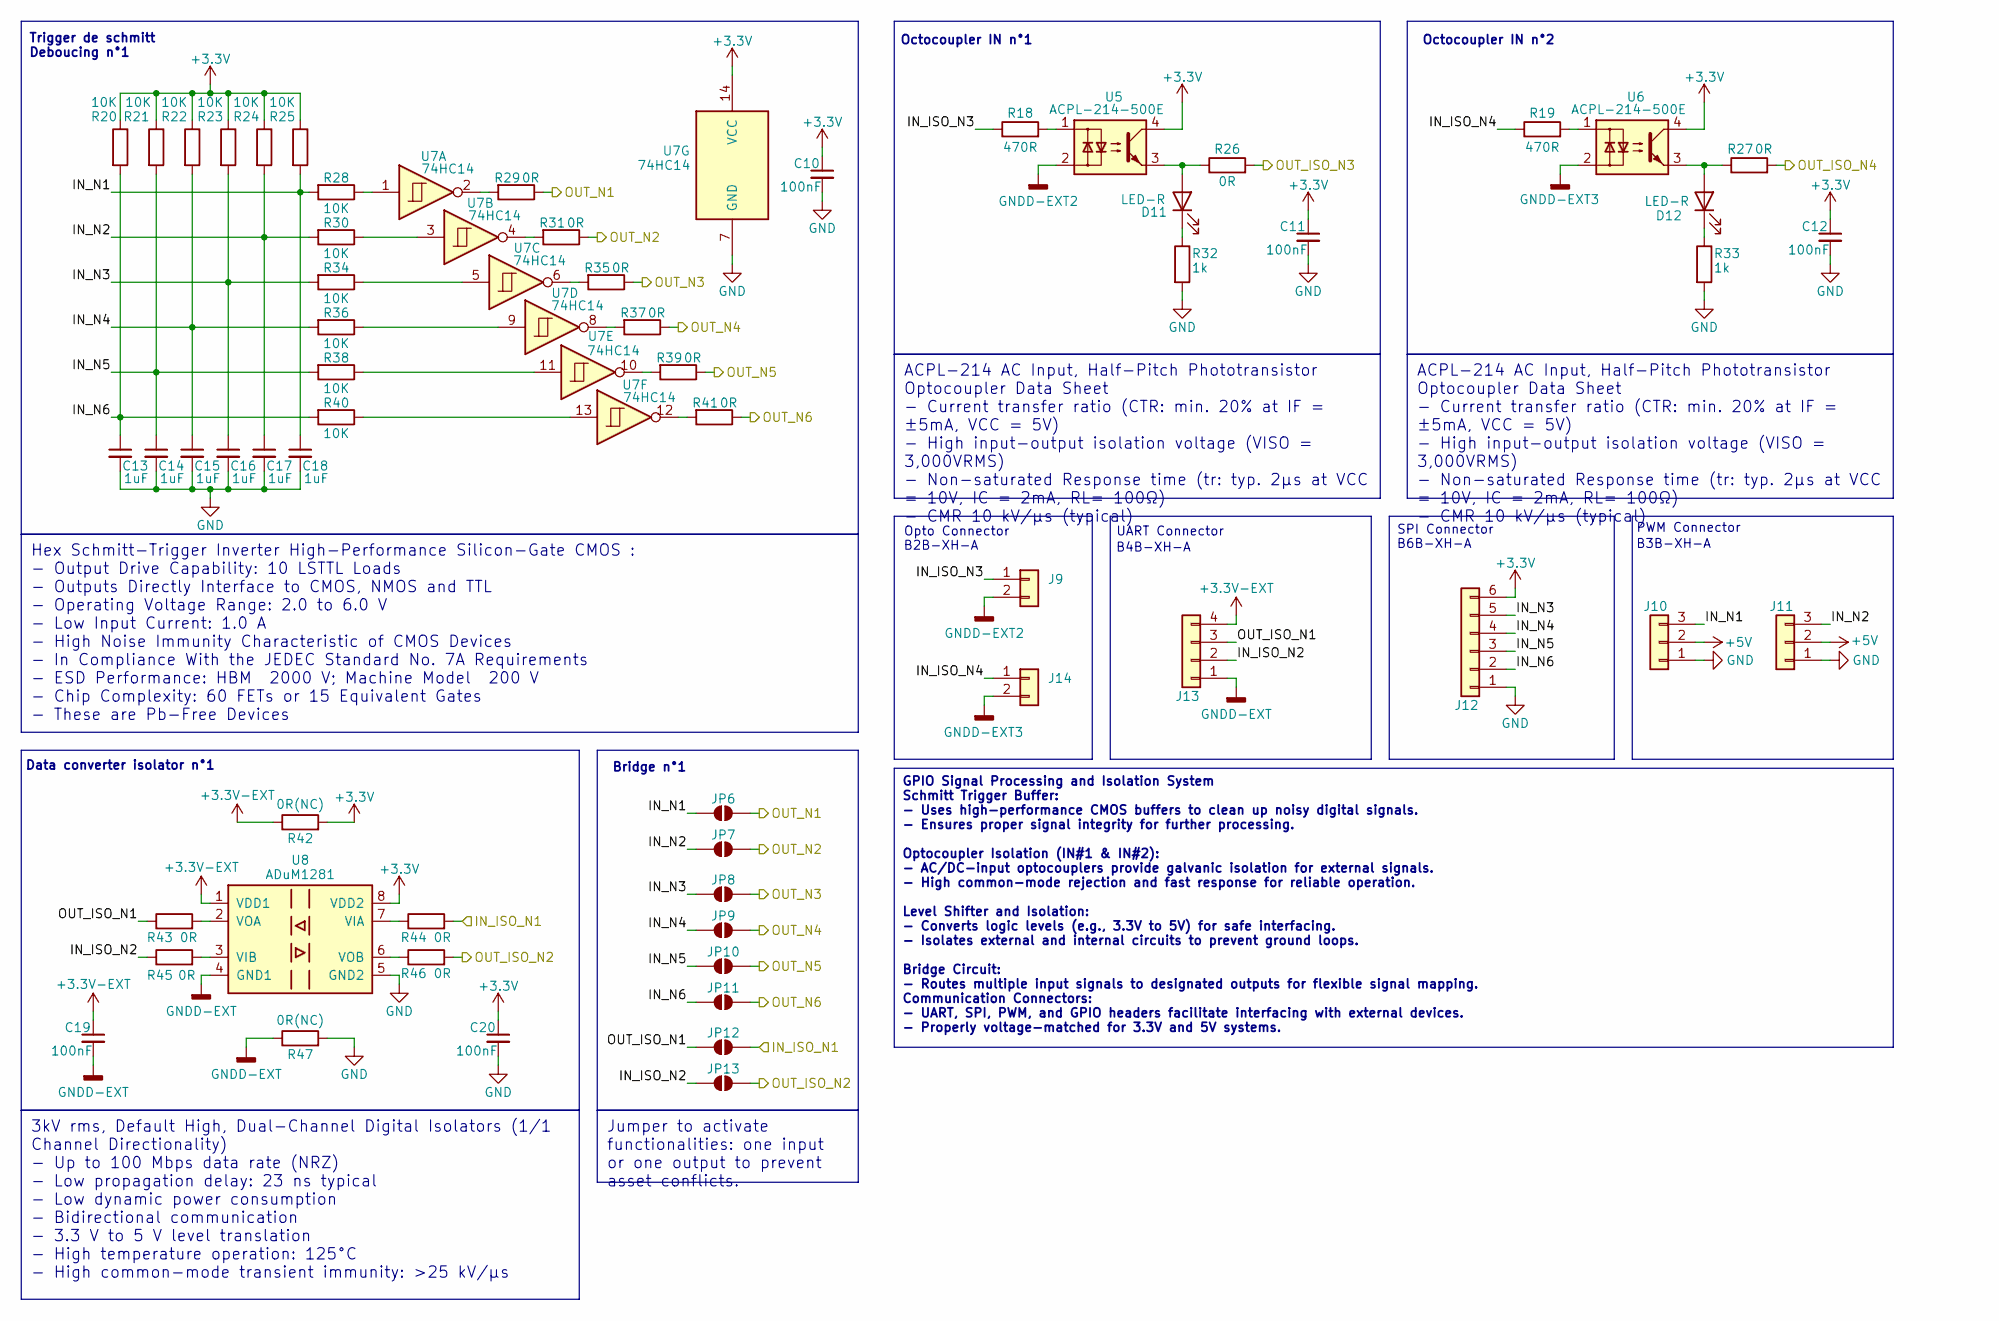
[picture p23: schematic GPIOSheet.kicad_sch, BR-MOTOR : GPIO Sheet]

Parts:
C10, C11, C12, C19, C20: 100nF; C_0603_1608Metric
C13, C14, C15, C16, C17, C18: 1uF; C_0603_1608Metric
D11, D12: LED-R; LED_0603_1608Metric
J9, J14: Conn_01x02; JST_XH_B2B-XH-A_1x02_P2.50mm_Vertical
J10, J11: Conn_01x03; JST_XH_B3B-XH-A_1x03_P2.50mm_Vertical
J12: Conn_01x06; JST_XH_B6B-XH-A_1x06_P2.50mm_Vertical
J13: Conn_01x04; JST_XH_B4B-XH-A_1x04_P2.50mm_Vertical
JP6, JP7, JP8, JP9, JP10, JP11, JP12, JP13: 0R(NC); R_0603_1608Metric
R18, R19: 470R; R_0603_1608Metric
R20, R21, R22, R23, R24, R25, R28, R30, R34, R36, R38, R40: 10K; R_0603_1608Metric
R26, R27, R29, R31, R35, R37, R39, R41, R43, R44, R45, R46: 0R; R_0603_1608Metric
R32, R33: 1k; R_0603_1608Metric
R42, R47: 0R(NC); R_0603_1608Metric
U5, U6: ACPL-214-500E; SOP-4_4.4x2.6mm_P1.27mm
U7: 74HC14; SOIC-14_3.9x8.7mm_P1.27mm
U8: ADuM1281; SOIC-8_3.9x4.9mm_P1.27mm

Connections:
+3.3V: C10.1, C11.1, C12.1, C20.1, J12.6, R20.1, R21.1, R22.1, R23.1, R24.1, R25.1, R42.2, U5.4, U6.4, U7.14 (VCC), U8.8 (VDD2); also elsewhere on the board
+3.3V-EXT: C19.1, J13.4, R42.1, U8.1 (VDD1)
+5V: J10.2, J11.2; also elsewhere on the board
/GPIOSheet/IN_ISO_N2: J13.2, JP13.1 (A), R45.1
/GPIOSheet/IN_ISO_N3: J9.1, R18.1
/GPIOSheet/IN_ISO_N4: J14.1, R19.1
/GPIOSheet/IN_N1: C18.1, J10.3, JP6.1 (A), R25.2, R28.2
/GPIOSheet/IN_N2: C17.1, J11.3, JP7.1 (A), R24.2, R30.2
/GPIOSheet/IN_N3: C16.1, J12.5, JP8.1 (A), R23.2, R34.2
/GPIOSheet/IN_N4: C15.1, J12.4, JP9.1 (A), R22.2, R36.2
/GPIOSheet/IN_N5: C14.1, J12.3, JP10.1 (A), R21.2, R38.2
/GPIOSheet/IN_N6: C13.1, J12.2, JP11.1 (A), R20.2, R40.2
/GPIOSheet/OUT_ISO_N1: J13.3, JP12.1 (A), R43.1
/IN_ISO_N1: JP12.2 (B), R44.2; also elsewhere on the board
/OUT_ISO_N2: JP13.2 (B), R46.2; also elsewhere on the board
/OUT_ISO_N3: R26.2; also elsewhere on the board
/OUT_ISO_N4: R27.2; also elsewhere on the board
/OUT_N1: JP6.2 (B), R29.1; also elsewhere on the board
/OUT_N2: JP7.2 (B), R31.1; also elsewhere on the board
/OUT_N3: JP8.2 (B), R35.1; also elsewhere on the board
/OUT_N4: JP9.2 (B), R37.1; also elsewhere on the board
/OUT_N5: JP10.2 (B), R39.1; also elsewhere on the board
/OUT_N6: JP11.2 (B), R41.1; also elsewhere on the board
GND: C10.2, C11.2, C12.2, C13.2, C14.2, C15.2, C16.2, C17.2, C18.2, C20.2, J10.1, J11.1, J12.1, R32.2, R33.2, R47.2, U7.7 (GND), U8.5 (GND2); also elsewhere on the board
GNDD-EXT: C19.2, J13.1, R47.1, U8.4 (GND1)
GNDD-EXT2: J9.2, U5.2
GNDD-EXT3: J14.2, U6.2
unnamed: D11.2 (A), R26.1, U5.3
unnamed: D11.1 (K), R32.1
unnamed: D12.2 (A), R27.1, U6.3
unnamed: D12.1 (K), R33.1
unnamed: R18.2, U5.1
unnamed: R19.2, U6.1
unnamed: R28.1, U7.1
unnamed: R29.2, U7.2
unnamed: R30.1, U7.3
unnamed: R31.2, U7.4
unnamed: R34.1, U7.5
unnamed: R35.2, U7.6
unnamed: R36.1, U7.9
unnamed: R37.2, U7.8
unnamed: R38.1, U7.11
unnamed: R39.2, U7.10
unnamed: R40.1, U7.13
unnamed: R41.2, U7.12
unnamed: R44.1, U8.7 (VIA)
unnamed: R45.2, U8.3 (VIB)
unnamed: R43.2, U8.2 (VOA)
unnamed: R46.1, U8.6 (VOB)

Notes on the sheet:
Hex Schmitt−Trigger Inverter High−Performance Silicon−Gate CMOS : - Output Drive Capability: 10 LSTTL Loads - Outputs Directly Interface to CMOS, NMOS and TTL - Operating Voltage Range: 2.0 to 6.0 V - Low Input Current: 1.0 A - High Noise Immunity Characteristic of CMOS Devices - In Compliance With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
3kV rms, Default High, Dual-Channel Digital Isolators (1/1 Channel Directionality) - Up to 100 Mbps data rate (NRZ) - Low propagation delay: 23 ns typical - Low dynamic power consumption - Bidirectional communication - 3.3 V to 5 V level translation - High temperature operation: 125°C - High common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
ACPL-214 AC Input, Half-Pitch Phototransistor Optocoupler Data Sheet - Current transfer ratio (CTR: min. 20% at IF = ±5mA, VCC = 5V) - High input-output isolation voltage (VISO = 3,000VRMS) - Non-saturated Response time (tr: typ. 2μs at VCC = 10V, IC = 2mA, RL= 100Ω) - CMR 10 kV/μs (typical)
Jumper to activate functionalities: one input or one output to prevent asset conflicts.
GPIO Signal Processing and Isolation System Schmitt Trigger Buffer: - Uses high-performance CMOS buffers to clean up noisy digital signals. - Ensures proper signal integrity for further processing. Optocoupler Isolation (IN#1 & IN#2): - AC/DC-input optocouplers provide galvanic isolation for extern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
Opto Connector
Octocoupler IN n°2
Octocoupler IN n°1
PWM Connector
UART Connector
Bridge n°1
B4B-XH-A
SPI Connector
B3B-XH-A
B2B-XH-A
Data converter isolator n°1
B6B-XH-A
Trigger de schmitt Deboucing n°1

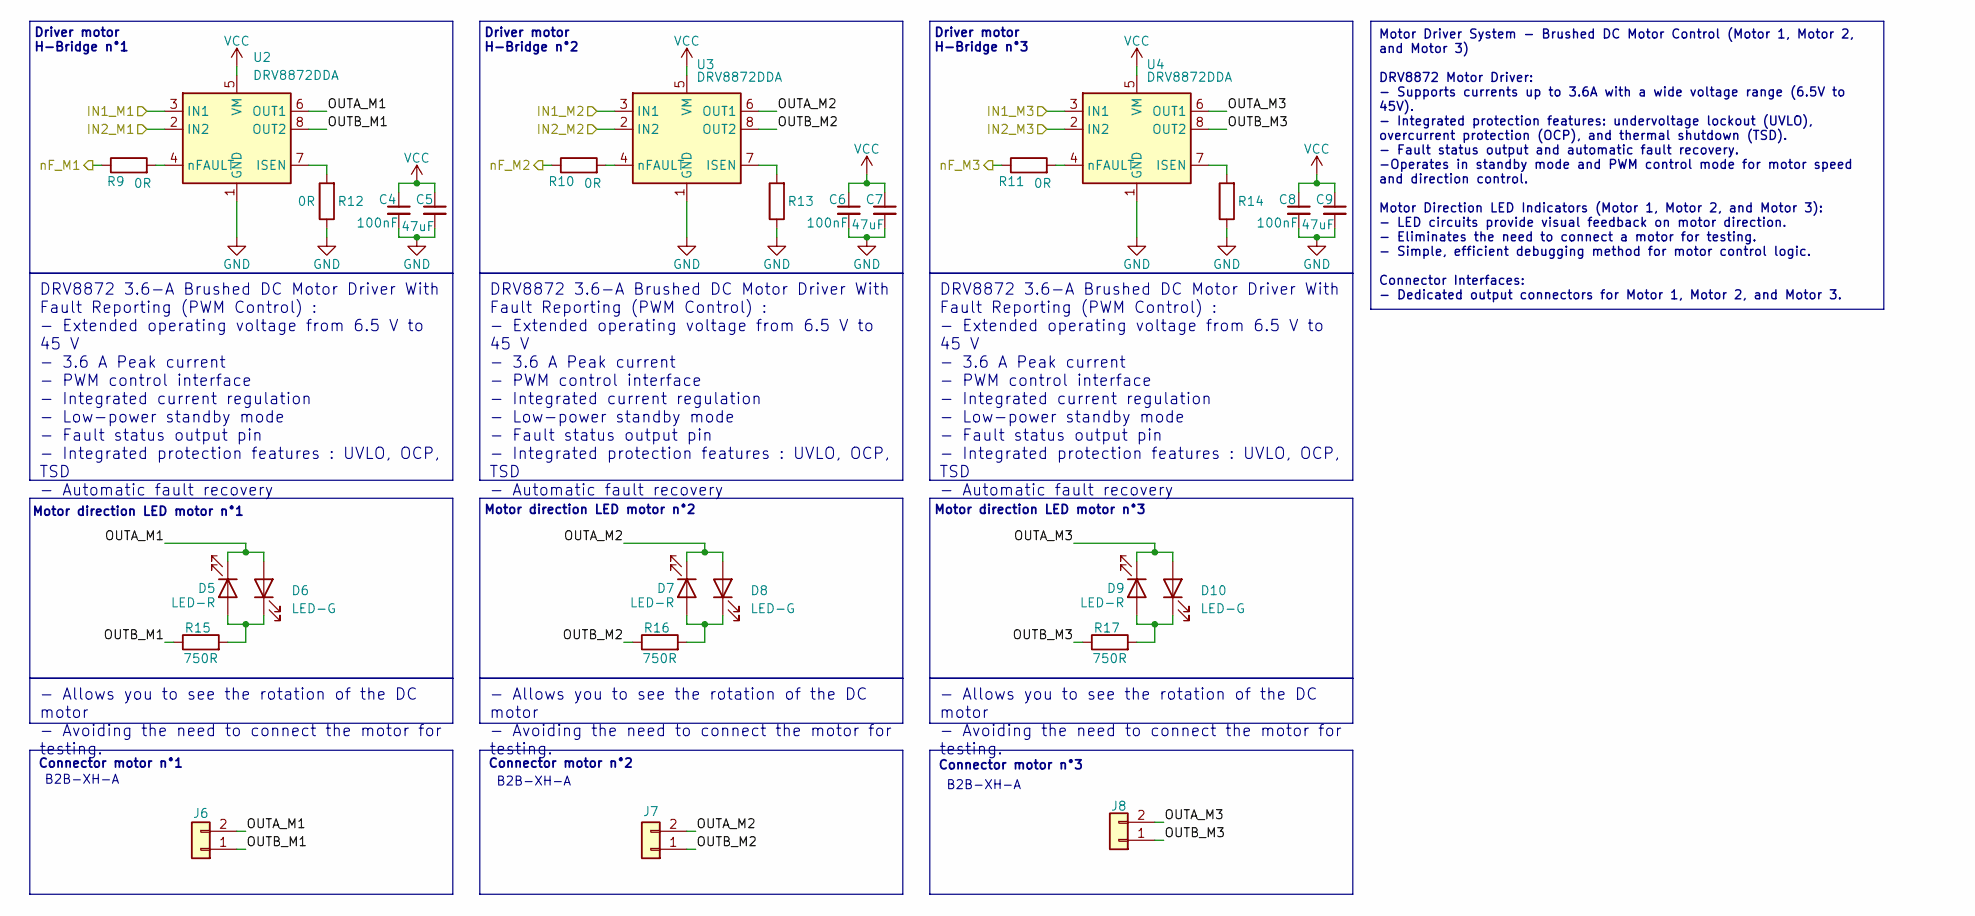
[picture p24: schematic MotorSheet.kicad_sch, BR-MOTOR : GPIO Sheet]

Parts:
C4, C6, C8: 100nF; C_0603_1608Metric
C5, C7, C9: 47uF; C_1206_3216Metric
D5, D7, D9: LED-R; LED_0603_1608Metric
D6, D8, D10: LED-G; LED_0603_1608Metric
J6, J7, J8: Conn_01x02; JST_XH_B2B-XH-A_1x02_P2.50mm_Vertical
R9, R10, R11, R12, R13, R14: 0R; R_0603_1608Metric
R15, R16, R17: 750R; R_0603_1608Metric
U2, U3, U4: DRV8872DDA; Texas_HTSOP-8-1EP_3.9x4.9mm_P1.27mm_EP2.95x4.9mm_Mask2.4x3.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

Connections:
/IN1_M1: U2.3 (IN1); also elsewhere on the board
/IN1_M2: U3.3 (IN1); also elsewhere on the board
/IN1_M3: U4.3 (IN1); also elsewhere on the board
/IN2_M1: U2.2 (IN2); also elsewhere on the board
/IN2_M2: U3.2 (IN2); also elsewhere on the board
/IN2_M3: U4.2 (IN2); also elsewhere on the board
/MotorSheet/OUTA_M1: D5.1 (K), D6.2 (A), J6.2, U2.6 (OUT1)
/MotorSheet/OUTA_M2: D7.1 (K), D8.2 (A), J7.2, U3.6 (OUT1)
/MotorSheet/OUTA_M3: D9.1 (K), D10.2 (A), J8.2, U4.6 (OUT1)
/MotorSheet/OUTB_M1: J6.1, R15.1, U2.8 (OUT2)
/MotorSheet/OUTB_M2: J7.1, R16.1, U3.8 (OUT2)
/MotorSheet/OUTB_M3: J8.1, R17.1, U4.8 (OUT2)
/nF_M1: R9.1; also elsewhere on the board
/nF_M2: R10.1; also elsewhere on the board
/nF_M3: R11.1; also elsewhere on the board
GND: C4.2, C5.2, C6.2, C7.2, C8.2, C9.2, R12.1, R13.1, R14.1, U2.1 (GND), U2.9 (GND), U3.1 (GND), U3.9 (GND), U4.1 (GND), U4.9 (GND); also elsewhere on the board
unnamed: D5.2 (A), D6.1 (K), R15.2
unnamed: D7.2 (A), D8.1 (K), R16.2
unnamed: D9.2 (A), D10.1 (K), R17.2
unnamed: R12.2, U2.7 (ISEN)
unnamed: R9.2, U2.4 (nFAULT)
unnamed: R13.2, U3.7 (ISEN)
unnamed: R10.2, U3.4 (nFAULT)
unnamed: R14.2, U4.7 (ISEN)
unnamed: R11.2, U4.4 (nFAULT)
VCC: C4.1, C5.1, C6.1, C7.1, C8.1, C9.1, U2.5 (VM), U3.5 (VM), U4.5 (VM); also elsewhere on the board

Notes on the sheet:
Motor Driver System - Brushed DC Motor Control (Motor 1, Motor 2, and Motor 3) DRV8872 Motor Driver: - Supports currents up to 3.6A with a wide voltage range (6.5V to 45V). - Integrated protection features: undervoltage lockout (UVLO), overcurrent protection (OCP), and thermal shutdown (TSD). - Fau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
- Allows you to see the rotation of the DC motor - Avoiding the need to connect the motor for testing.
DRV8872 3.6-A Brushed DC Motor Driver With Fault Reporting (PWM Control) : - Extended operating voltage from 6.5 V to 45 V - 3.6 A Peak current - PWM control interface - Integrated current regulation - Low-power standby mode - Fault status output pin - Integrated protection features : UVLO, OCP, TS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
Driver motor H-Bridge n°3
Connector motor n°2
Driver motor H-Bridge n°1
B2B-XH-A
Connector motor n°3
Driver motor H-Bridge n°2
Motor direction LED motor n°1
Motor direction LED motor n°2
Motor direction LED motor n°3
Connector motor n°1

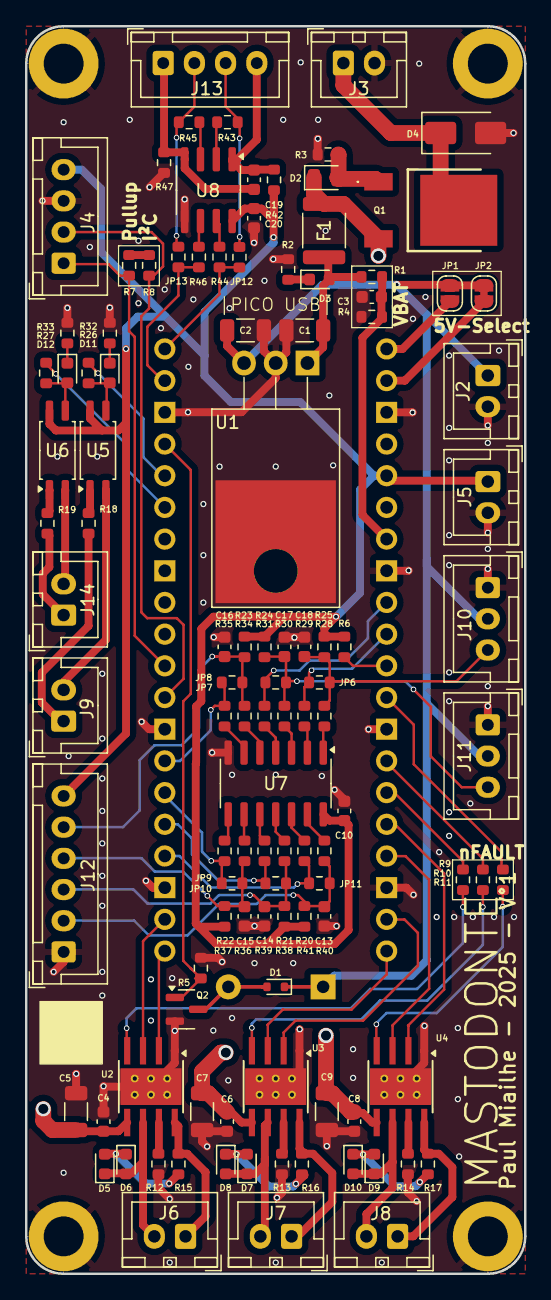
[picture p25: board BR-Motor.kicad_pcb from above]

Board: 4 copper layers, 40.0 x 100.0 mm, 117 parts (1 on the bottom side), 87 nets.

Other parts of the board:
REF1, REF2, REF3, REF4: MountingHole_3.2mm_M3_DIN965_Pad

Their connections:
GND: REF1.1, REF2.1, REF3.1, REF4.1; also elsewhere on the board

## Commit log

2025-04-01 reorganize files
    [PCB-MASTODONTE.dxf]
2025-04-01 rename folders
    [bom-JLCPCB.xls]
2025-04-01 Create BR-Motor Dessin v2.pdf
2025-04-01 update folders
    [PCB-MASTODONTE.dxf, bom-JLCPCB.xls]
2025-04-05 Update PDF shematic
    [BR-Motor.kicad_sch, GPIOSheet.kicad_sch, MotorSheet.kicad_sch]
2026-06-16 Update README with BR Mini Sensor information
    Added details about the BR Mini Sensor module and hardware configuration precautions.
2026-06-16 Revise BR Mini Sensor description and add image
    Updated the BR Mini Sensor section to clarify its compatibility and added an image link.
2026-06-16 Adjust image width for BR Mini Sensor
    Updated image width in README for better display.

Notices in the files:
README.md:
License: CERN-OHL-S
